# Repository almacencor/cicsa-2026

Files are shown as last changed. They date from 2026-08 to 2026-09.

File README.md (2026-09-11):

CICSA WRO 2026 Banner

# WRO 2026 Future Engineers — Team CICSA
### National Final · Mexico · Season 2026

This is the official repository of **Team CICSA** for the WRO 2026 Future Engineers National Final. It contains all engineering materials for our self-driving vehicle: source code, wiring diagrams, 3D models, photos, and a full engineering journal documenting our design process.

---

## Follow us!

| Facebook | YouTube | Instagram |
|---|---|---|
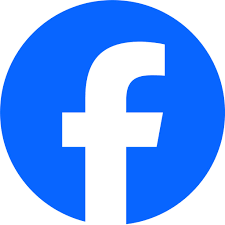
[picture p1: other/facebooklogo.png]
Facebook (https://www.facebook.com/share/1A1hz6zQSn/)
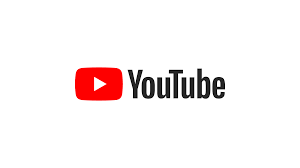
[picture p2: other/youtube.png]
YouTube (https://www.youtube.com/@CICSA_Academia)
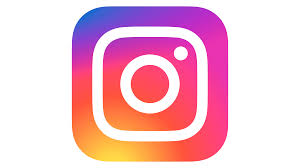
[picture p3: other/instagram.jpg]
Instagram (https://share.google/ZzGMFZOurGsjhWN2D)
|  |  |  |

---

## Contents

**Folders**
- [📁 Models](./models/) — 3D printable parts (STL/F3D files)
- [📁 Other](./other/) — Engineering logbook and supplementary materials
- [📁 Schemes](./schemes/) — Wiring diagrams and electrical schematics
- [📁 Src](./src/) — All source code (Raspberry Pi Python — single-controller architecture)
- [📁 T-photos](./t-photos/) — Team photos (official + funny)
- [📁 V-photos](./v-photos/) — Vehicle photos (6 angles required)
- [📁 Video](./video/video.md) — Performance video links

**Index**
- [The team](#the-team)
- [The challenge](#the-challenge)
- [Robot overview](#robot-overview)
- [Mobility management](#mobility-management)
- [Power and sensor management](#power-and-sensor-management)
- [Software architecture](#software-architecture)
- [Obstacle management](#obstacle-management)
- [Systems thinking and engineering decisions](#systems-thinking-and-engineering-decisions)
- [Robot construction guide](#robot-construction-guide)
- [Engineering materials](#engineering-materials)
- [Performance videos](#performance-videos)
- [Digital engineering logbook](./other/README.md)
- [Final remarks and future work](#final-remarks-and-future-work)
- [References](#references)

---

## The team

**CICSA WRO 2026 — Future Engineers**

**Coach: Sergio Iván Hernández Ruiz**

Coach Sergio Iván provides the technical guidance and leadership required to keep Team CICSA on track. With extensive experience in robotics, he helps us navigate complex engineering challenges, refine our designs, and develop solutions that work in competitive environments. He has been director of the CICSA robotics academy since 2015 and has participated in WRO events since 2019.

---

**Gildardo Garcia** — Age 17 · Centro de Estudios Tecnológicos Industrial y de Servicios 128

Gildardo is responsible for the programming. He participated in the 2019 WRO Regional in Guadalajara in the primary category, where he obtained 2nd place. For the 2026 championship, he is responsible for programming and calibrating the sensors to ensure they function correctly.

---

**Sergio Amid Hernández González** — Age 20 · Software Engineering, Kuepa University

Sergio Amid leads the design and construction of the robot's 3D parts. He has participated in numerous competitions: 2019 WRO Regional in Guadalajara (1st place, preparatory category), 2024 WRO National in Mexicali (1st place, preparatory category), and represented Mexico at the WRO World Championship in Italy in 2024.

---

**Diego Pereida Arochi** — Age 18 · United States Air Force Avionics technician

Diego is responsible for PID control, motor/servo driver integration, and LIDAR sensor tuning, all running natively on the Raspberry Pi. He has competed in the FIRST Robotics Competition in both the United States and Mexico, achieved 1st place at WRO 2025 Mexicali, and alongside Sergio Amid represented Mexico at the WRO Italy 2024 Open World Championship. Currently in boot camp in San Antonio, Texas, and wasn't able to attend the national championship.

[📁 T-photos](./t-photos/)

[▲ Menu](#contents)

---

## The challenge

The WRO 2026 Future Engineers challenge requires teams to build a fully autonomous self-driving vehicle that competes in two rounds:

**Open Challenge:** The vehicle must complete three (3) laps on a track with randomly placed inner walls. Direction (clockwise or counter-clockwise) is revealed at competition time. No obstacles are present; the goal is clean navigation and lap time.

**Obstacle Challenge:** The vehicle must complete three (3) laps on the same track, this time with randomly placed red and green traffic sign pillars. The robot must:
- Pass to the **right** of a **red** pillar
- Pass to the **left** of a **green** pillar
- Not knock over any pillar
- After completing three laps, locate the magenta-bordered parking zone and execute a **parallel parking maneuver**

Scoring is based on: laps completed, obstacles respected, parking success, lap time, and documentation quality (engineering journal and this GitHub repository).

Our robot addresses these requirements using:
- **LIDAR** (RPLidar A1M8) for 360° distance mapping, sector-based wall following, and initial track-direction detection
- **Computer vision** (OpenCV on Raspberry Pi), used in the Obstacle Challenge program for traffic sign color detection and parking-zone location
- **PID control**, running natively in Python on the Raspberry Pi via `gpiozero`, for closed-loop steering during wall following
- **Hardware-timed PWM** (via the `pigpio` pin factory backing `gpiozero`) driving the servo and motor drivers from Raspberry Pi GPIO pins

For full game rules, visit the [WRO Official Site](https://wro-association.org/).

[▲ Menu](#contents)

---

## Robot overview

| Front | Back | Top |
|---|---|-----|
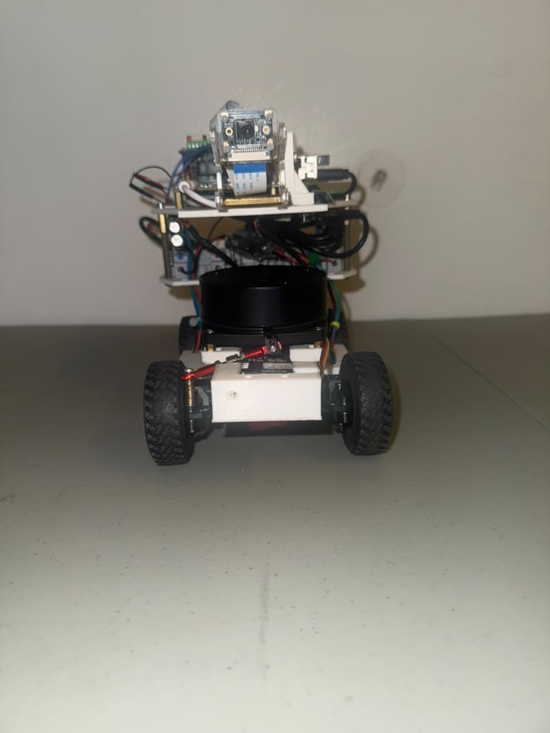
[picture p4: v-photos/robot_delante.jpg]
Front view
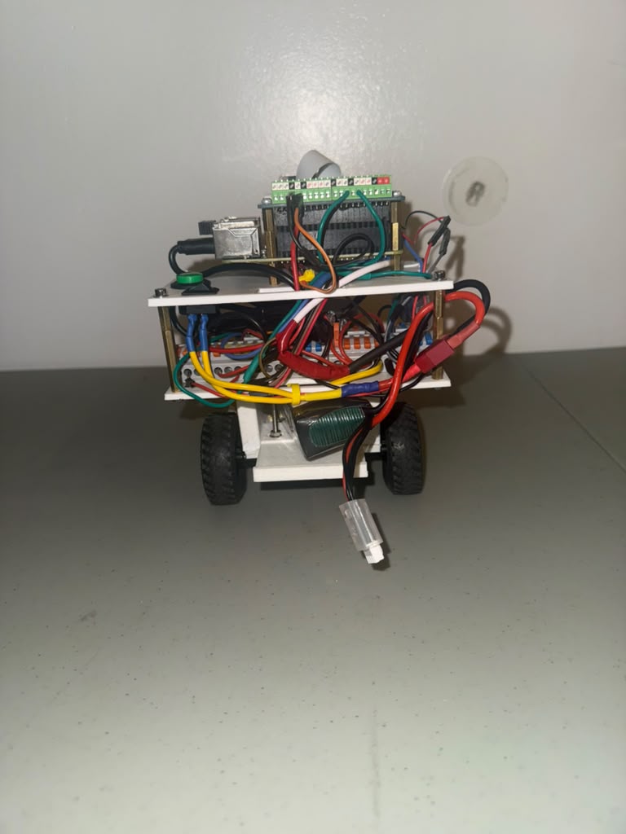
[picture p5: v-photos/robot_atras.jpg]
Back view
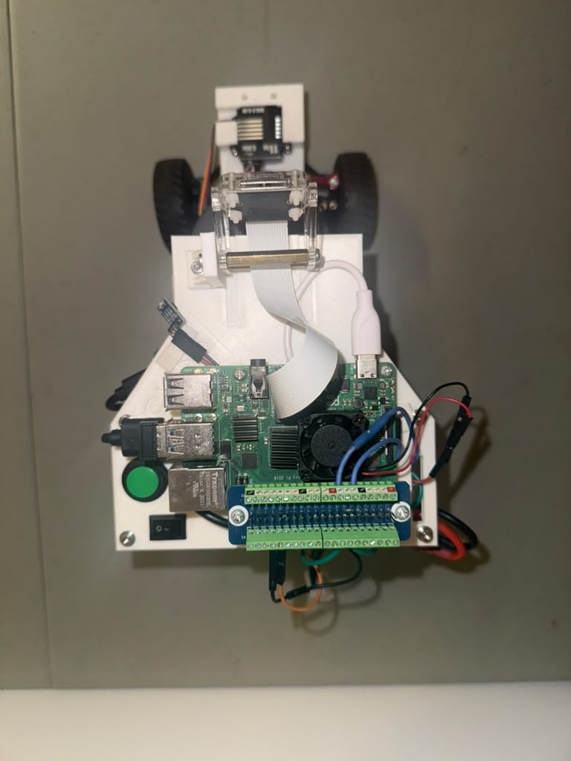
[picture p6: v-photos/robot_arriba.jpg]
Top view
|  |  |  |

| Bottom | Left | Right |
|---|---|---|
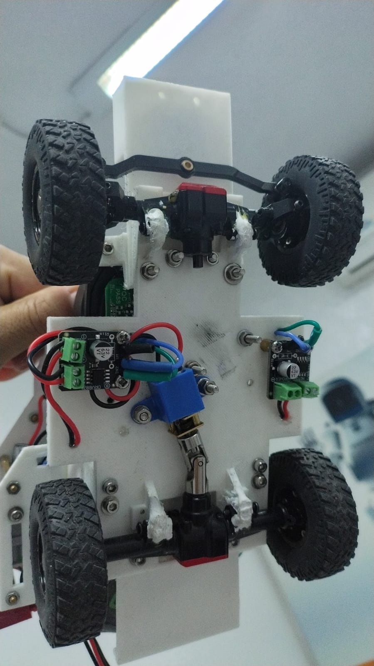
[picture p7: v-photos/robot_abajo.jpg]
Bottom view
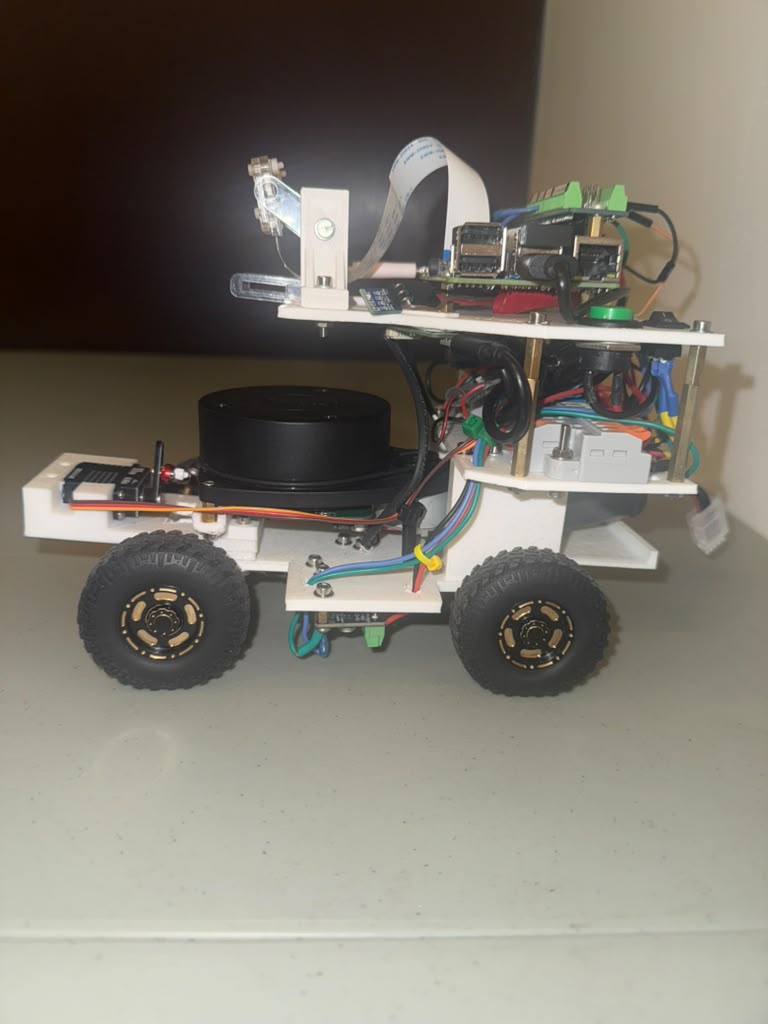
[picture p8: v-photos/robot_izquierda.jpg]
Left view
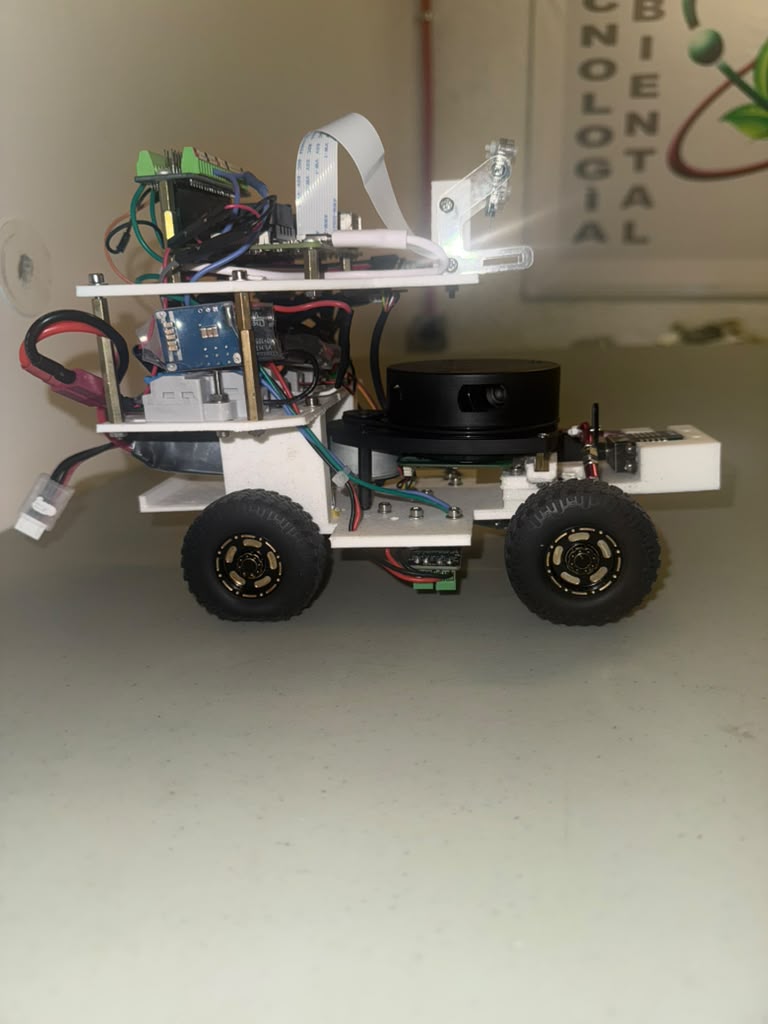
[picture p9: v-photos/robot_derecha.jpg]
Right view
|  |  |  |

| Dimension | Value |
|---|---|
| Length | ~230 mm |
| Width | ~145 mm |
| Height | ~190 mm |
| Weight | ~1174 g |

> **Note for judges:** Exact dimensions measured with calipers are documented in the engineering logbook. Robot must be under 300 mm × 200 mm per WRO vehicle regulations.

[▲ Menu](#contents)

---

## Mobility management

### Chassis and drive system

Our chassis employs a **rear-wheel drive** (RWD) system using a 400-RPM N20 motor, capped at 50% power to optimize battery life and improve LiDAR readings during turns—as higher speeds caused the LiDAR to struggle, thereby increasing the margin of error. The motor connects to the wheels via a differential to enable tighter turns, while the front end features an Ackermann steering system.

**Drive motor: N20 DC 12V, 400 RPM**

We selected the **N20 400 RPM variant** after testing 500 RPM and 1000 RPM versions of the same motor family. The higher-RPM motors caused the robot to overshoot turns and made PID tuning unstable at low speeds. We limit the motor power to just **200 rpm** (50% power) so that the robot has better PID control when turning in the shortest possible time and with the 2.09in diameter wheels, the linear speed is approximately:

```
2.09 in x 2.54 = 5.3086
R=5.3086 / 2=2.654
C=3.1416 x 5.3086 = 16.667
16.667 cm/rev x 200rev/min = 3335.4 cm/min
3335.4 / 60 = 55.59cm/s
linear speed 55.6 cm/s
```

This ~55.6 cm/s base speed provides enough controllability for the PID loop while still completing three laps in a competitive time. The N20 at 12V produces ~1.5 kg·cm of stall torque, sufficient to move our 1.179 kg robot including a safety margin for carpet-surface friction. In code, drive speed is set as a duty-cycle fraction (`target_velocity`, currently 0.5) rather than a raw RPM value.

**Steering: DIYmall 11KG Mini All-Metal Digital Servo**

The front axle uses the DIYmall 11KG coreless digital servo for steering. We chose an 11 kg·cm servo (rather than a lighter 3–5 kg·cm servo) because our front wheel assembly includes a 4mm-to-3mm steering shaft that creates mechanical friction. The heavier servo ensures fast, accurate response to PID commands without positional lag.

In software, the servo is driven through `gpiozero`'s `AngularServo` class (backed by the `pigpio` pin factory for hardware-timed pulses), configured for a ±90° mechanical range with 0.5–2.5 ms pulse widths and a software center of 0°. Two calibration constants trim this in code:
- `STEERING_LIMIT = 40` — clamps every requested steering command to ±40°, well inside the mechanical range, to protect the linkage.
- `CENTER_OFFSET = -20` — a fixed trim added after clamping, to correct for the assembly's slight physical off-center bias, rather than a separate one-time calibration script.

**Wheels: TRX4M 1/18 scale**

These wheels provide a balance between grip and rolling resistance. Their 2.09IN outer diameter was used in all speed calculations above.

**Turning radius estimation**

With our wheelbase of approximately 120mm and a software steering limit of ±40°, the minimum turning radius is approximately 165mm. This is well within the WRO track corner geometry.

### Steering and assembly photos

> See [📁 Models](./models/) for all 3D-printed STL files for the chassis plate, LIDAR tower, camera mount, and servo bracket.
> See [📁 V-photos](./v-photos/) for step-by-step assembly photos.

[▲ Menu](#contents)

---

## Power and sensor management

### Power system architecture
|Component | Operating Voltage	| Approx. Typical Current	| Approx. High/Maximum Current	| Approx. Power |
|---|---|---|---|---|
|Raspberry Pi 4B	| 5 V	| 0.7–1.2 A	| ~1.5–2.0 A	| 3.5–10 W |
|Freenove Camera	| 5 V	| ~0.1–0.3 A	| ~0.3–0.5 A	| 0.5–2.5 W |
|LiDAR A1M8	| 5 V	| ~0.12–0.18 A	| ~0.2 A	| 0.6–1 W |
|Mini Servo, 24.3 lb, 180°	| 5 V	| ~0.2–0.8 A	| ~1.5–2.0 A*	| 1–10 W |
|N20 Motor , 400 RPM	| 11.1 V via DRV8871	| ~0.2–0.8 A	| ~1.5 A or higher*	| ~2–17 W |
|MPU 6050 | 5V | 3.9mA | 5mA | 13mA |

**Battery:** OVONIC 3S 11.1V, 2200 mAh

We use an 11.1V OVONIC 3S battery; although it nominally provides 12.6V, the voltage drops to 11.1V under load. It is capable of powering the N20 motor, as the motor primarily relies on current—which the 8871 driver supplies. A 2200 mAh capacity gives an estimated runtime of:1.11 hours if the motors are in a middle range of work and the processor is not demanding to much energy 

```
1.20+0.30+0.18+0.50+0.0039=2.1839
P5v = 5x2.18 = 10.9W
Pmotor = 11.1x0.80 = 8.88W
Ptotal = 10.9+8.88 = 19.78W
90% regulator efficiency = 21.98W
11.1V x 2.2Ah = 24.42Wh
Runtime = 24.42Wh/21.98W = 1.11H

```

Three competition rounds are estimated at under 10 minutes total, giving more than 5× safety margin.

**Voltage regulation:**

A DC-DC buck converter steps the 11.1V battery down to a stable 5V 5A rail for the Raspberry Pi, LIDAR, and servo. The motor drivers (DRV8871) take 12V directly from the battery to drive the N20 motors. The Raspberry Pi's own 3.3V GPIO pins drive the DRV8871 logic inputs and the servo PWM line directly — no intermediate microcontroller or level shifting is required, since the DRV8871's logic inputs and standard hobby servos both accept 3.3V signal levels.

**Wiring diagram:**

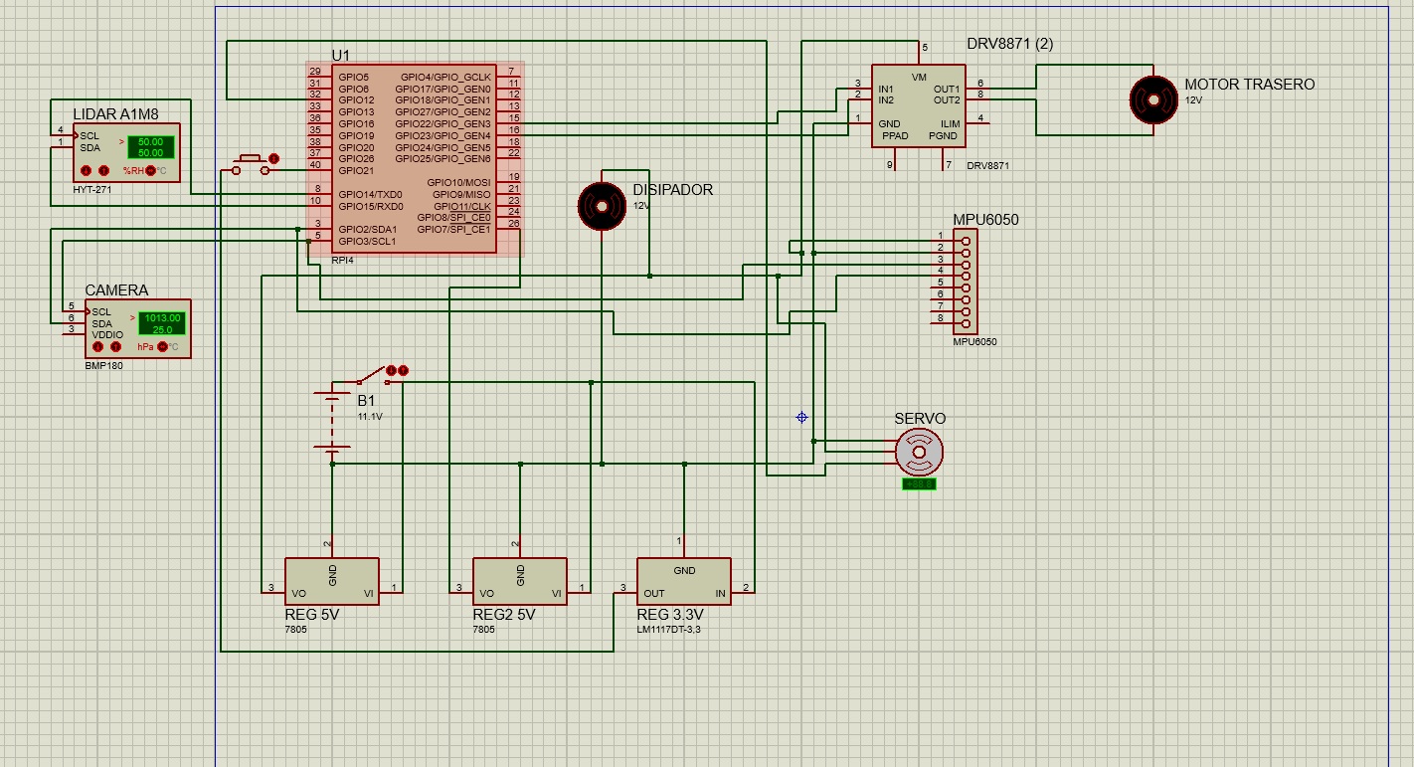
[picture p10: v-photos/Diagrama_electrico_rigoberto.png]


> See [📁 Schemes](./schemes/) for the full wiring schematic (Fritzing + PDF export).

Actual GPIO assignments:
- Battery (+) → DRV8871 (1) VM IN and Buck Converter IN
- Buck converter 5V OUT → Raspberry Pi USB-C, LIDAR 5V, Servo signal rail
- Raspberry Pi **GPIO 2, 3** → SCL and SDA 
- Raspberry Pi **GPIO 23** → Rear-motor DRV8871 IN1 (forward)
- Raspberry Pi **GPIO 22** → Rear-motor DRV8871 IN2 (backward) — this is the channel actually driving the robot
- Raspberry Pi **GPIO 12** (hardware PWM via `pigpio`) → Servo signal wire

Each axle's driver has its own independent forward/backward pin pair, which is what allows the front motor to be enabled or disabled purely in software.

### Sensor selection and placement

**RPLidar A1M8 (1 unit) — top-center mount**

The LIDAR provides 360° distance scanning at up to 8m range. We mount it at the top center of the robot so it has unobstructed line-of-sight to the track walls. It is the primary sensor for both the open-challenge wall-following algorithm and the initial track-direction detection at start-up, and it also supports close-range distance checks in the Obstacle Challenge program (parking-wall proximity).

Rather than reading raw single-beam distances, the code partitions each scan into three angular sectors and runs a small DSP pipeline before using the data (see [Software architecture](#software-architecture) for details):
- Front sector: −5° to +5°
- Left sector: 255° to 285°
- Right sector: 75° to 105°

**Freenove 8MP Camera (1 unit) — front center, elevated 80mm**

Used by the Obstacle Challenge program (not present in `wro2026_open_e.py`). The camera is mounted forward-facing at 80mm height, which gives a field of view that captures both the floor zone immediately ahead of the robot and traffic signs at their actual height on the track. Elevation was determined through testing: lower mounting caused the camera to see too much floor and miss vertical pillar colors; higher than 90mm clipped the near field.

**Sensor calibration:**

- LIDAR: Uses RPLidar SDK default factory calibration. Points below 150mm or above 6000mm are discarded as out-of-range/self-mapping noise (see DSP pipeline below).
- Steering: mechanical/electrical zero-offset is trimmed with the `CENTER_OFFSET` constant in code rather than a separate calibration script.
- Camera (Obstacle Challenge program): white balance set to auto; HSV color thresholds for red/green calibrated under venue lighting the day before the event and stored as constants in the config file.

[▲ Menu](#contents)

---

## Software architecture

### System overview

All decision-making and control runs in a single process on the **Raspberry Pi 4B (Python 3)**, using the `gpiozero` library for motor/servo control with its **pigpio pin factory** (set via `GPIOZERO_PIN_FACTORY = 'pigpio'`) so PWM pulses are generated with hardware timing (via the Pi's DMA controller) instead of in Python's own execution thread. This means servo and motor pulses stay precisely timed even if the Python control loop itself is briefly delayed by the OS scheduler.

This repository currently documents two separate programs:
- **`wro2026_open_e.py` (Open Challenge)** — LIDAR-only: sector-based distance sensing, DSP filtering, a start-up direction-detection routine, and a velocity-form PID wall follower. **No camera, no OpenCV, no obstacle/parking logic exists in this file.**
- **Obstacle Challenge program** — extends the same LIDAR/PID/motor foundation with the camera-based color detection and parking sequence described in [Obstacle management](#obstacle-management).

### Open Challenge — quick overview

These diagrams are meant to be walked through verbally in under a minute.

**Flow — what the robot does, in order:**

```mermaid
flowchart TD
    A["Start"] --> B["Initialize<br/>(motors off, servo centered)"]
    B --> C["Find track direction<br/>(LIDAR spots the first opening)"]
    C --> D["Follow the wall<br/>(PID keeps it centered)"]
    D --> E["Turn the corner"]
    E --> F{"Finished all laps?"}
    F -- No --> D
    F -- Yes --> G["Slow final stretch, then stop"]
```

**States — what mode the robot is in:**

```mermaid
stateDiagram-v2
    [*] --> Starting
    Starting --> FindingDirection
    FindingDirection --> FollowingWall
    FollowingWall --> TurningCorner
    TurningCorner --> FollowingWall: more laps left
    TurningCorner --> Finishing: laps complete
    Finishing --> Stopped
    Stopped --> [*]
```

### Open Challenge — program flow

- **`initialize_system()`** — zeroes actuators (motors stopped, steering centered) before anything else runs.
- **LIDAR worker thread (`lidar_worker_thread`)** — a daemon thread that continuously reads scans from the RPLidar, splits each scan into front/left/right sectors by angle, runs the DSP pipeline below, and writes the resulting distances into shared global variables under a lock (`lidar_lock`) for the main thread to read.
- **`execute_start_sequence()`** — drives forward slowly while watching the left and right sectors. The first time one side reports a gap >1000mm while the front is ≤750mm, that's read as the track's first open corner; the robot executes a blind, timed 90° turn toward that opening and locks in which wall it will track (`control_direction`) for the rest of the run. Lap progress after that is tracked by counting a fixed number of turns rather than detecting a start/finish line.
- **`pid_wall_follower()`** — the closed-loop distance-holding routine, described in detail below.
- **`execute_90deg_left_turn()` / `execute_90deg_right_turn()`** — open-loop, timed turns (steer to ±40°, hold ~0.95s, recenter) used to negotiate each corner once the PID segment approaches it.
- **`terminate_system()`** — stops both motors and recenters steering; also runs on `KeyboardInterrupt` or any unhandled exception, so the robot fails safe.

### LIDAR signal processing (`filter_lidar_zone`)

Each angular sector's raw `(distance, angle)` points go through a small NumPy/SciPy pipeline before being used for control:

1. **Range filter** — discard points outside 150–6000mm (150mm excludes the robot's own chassis from self-mapping).
2. **Dropout interpolation** — missing/out-of-range samples are linearly interpolated (`np.interp`) from neighboring valid points rather than left as gaps.
3. **Median filter** — a wrapped median filter (window size 3) smooths the sector and rejects specular multi-path reflections.
4. **Step-discontinuity rejection** — the first-order difference between consecutive filtered points is checked against a 500mm gradient threshold; points that jump too fast between adjacent readings are dropped as likely noise.

The closest valid point in each sector is then taken as that sector's representative distance (front/left/right).

### PID controller (velocity-form, Raspberry Pi)

The actual PID implementation in `pid_wall_follower()` is a **velocity-form (incremental) PID**, not the textbook positional form:

```python
output = int(
    kp * (error - p_error)
    + (ki * error)
    + (kd * (error - (2 * p_error) + p_error_2))
    + p_output
)
output = min(max(output, -40), 40)
```

**Tuned values (current, in code):**
- `kp = 1.2` (proportional term, applied to the error delta)
- `ki = 0.0` (integral term currently disabled)
- `kd = 0.5` (derivative-of-error term, using a second-order error history)
- Sample time `T = 0.005s` — a ~200Hz control loop

The raw output is passed through `sanitize_control_signal()`, a rolling-median filter over the last 5 outputs: if a new value would jump more than 15° away from the recent median, it's replaced with that median instead, damping single-cycle spikes before they reach the servo. The sanitized value is what's actually sent to `set_steering_angle()`.

A safety early-exit ("CUELLO"/bottleneck check) is built into the long wall-follow segment: if the front sector reports ≤725mm after at least 250 cycles during the main 11-lap-loop call (not the short finishing call), the function exits early rather than continuing to drive toward a wall it's approaching too fast.

### Motor and steering actuation

- **`drive_forward_rwd()` / `drive_backward_rwd()` / `stop_rwd()`** — The motor is connected to the rear-wheel differential to provide mobility for the robot.
- **`set_steering_angle()`** — clamps the requested angle to `±STEERING_LIMIT` (40°), adds the `CENTER_OFFSET` trim (−20°), and writes the result to the `AngularServo`.

### Code structure

```
src/
└── raspberry_pi/
    ├── wro2026_open_e.py    # Open Challenge: state machine, LIDAR DSP, PID wall follower, motor/servo control
    └── (obstacle challenge program — vision/color detection, parking; separate file)
```

`wro2026_open_e.py` is a single self-contained script. Splitting it into separate modules (vision, LIDAR, PID, motor control) is on our list for a future cleanup pass.

[▲ Menu](#contents)

---

## Obstacle management

**Everything in this section describes the separate Obstacle Challenge program, which is not part of `wro2026_open_e.py`.** The Open Challenge script has no camera input and no color/parking logic.

# WRO 2026 Future Engineers - Obstacle Challenge

Autonomous vehicle developed for the *WRO 2026 Future Engineers Obstacle Challenge*. The system runs on a Raspberry Pi 4 and combines a 2D LiDAR, a camera, and an MPU6050 inertial sensor to follow walls, determine the driving direction, avoid colored traffic pillars, negotiate corners, recover from critical situations, and complete the required laps.
 
> Main program: wro2026_obstacle.py

## Project goals

The controller was designed around five priorities:

- Compliance with the WRO Future Engineers obstacle rules.
- Repeatable behavior with different battery levels.
- Sensor validation instead of acting on isolated measurements.
- A clear finite-state machine for testing and debugging.
- Recovery from temporary faults without immediately ending the run.

## Hardware

| Component | Purpose | Connection |
|---|---|---|
| Raspberry Pi 4 | Main computer and control coordinator | Central controller |
| RPLidar A1 | Front and lateral distances, wall geometry, open spaces, and corner detection | USB serial, normally /dev/ttyUSB0 |
| Freenove IMX219 camera | Red/green pillar detection and image position | Raspberry Pi CSI interface |
| MPU6050 | Angular velocity, accumulated heading, and 90-degree turn confirmation | I2C: SDA GPIO 2, SCL GPIO 3 |
| Ackermann steering servo | Front steering angle | GPIO 12 |
| Rear DC motor and driver | Forward and reverse movement | GPIO 23 and GPIO 22 |
| MPU6050 | Know the robot position | GPIO 2 and GPIO 3 |

The LiDAR convention used by the software is:

- 0°: front
- 90°: right
- 180°: rear
- 270°: left

Positive steering angles turn left; negative angles turn right.

## System architecture

The sensors run in independent background threads. Each thread publishes its newest measurement with a sequence number and timestamp. A single fixed-rate controller reads the latest snapshots at *40 Hz*, validates them, executes the active state, and sends commands to the steering servo and rear motor.

mermaid
flowchart TD
    CAM["Camera<br/>pillar color, x, bottom, area"]
    LIDAR["RPLidar A1<br/>front, left, right, wall angle"]
    MPU["MPU6050<br/>heading and angular change"]

    SNAP["Time-stamped sensor snapshots"]
    VALID["Validation and filtering"]
    FSM["40 Hz finite-state controller"]
    ACT["Steering servo and rear motor"]
    TELE["CSV telemetry"]

    CAM --> SNAP
    LIDAR --> SNAP
    MPU --> SNAP
    SNAP --> VALID --> FSM
    FSM --> ACT
    FSM --> TELE

## How each sensor is used

### RPLidar A1

The LiDAR is the main geometric sensor. Its scans are divided into angular sectors to obtain front, left, and right distances. Recent measurements are filtered with medians and checked for minimum point count, age, physical range, and impossible jumps.

It supports:

- Corridor centering before the driving direction is known.
- Outer-wall following during normal sections.
- Selection of the closest reliable wall during pillar avoidance.
- Detection of the front wall before a corner.
- Verification that enough space exists during reverse and corner exit.
- Recovery when a distance becomes critical or the LiDAR stops updating.

### Camera

The IMX219 camera detects red and green traffic pillars. The image pipeline applies a region of interest, color segmentation, blob filtering, and geometric plausibility checks.

For every candidate, the controller considers:

- Color: red or green.
- Horizontal position (x).
- Bottom position in the image.
- Blob area and shape.
- Agreement between two independent distance estimates.

The color determines the legal passing side:

| Pillar | Robot passes on | Pillar remains on |
|---|---|---|
| Red | Right | Left side of the robot |
| Green | Left | Right side of the robot |

A short hold period prevents the maneuver from ending because of one missed camera frame. After the pillar disappears, the controller completes the crossing using LiDAR distance and MPU6050 heading.

### MPU6050

The MPU6050 is calibrated while the robot is completely stationary. The Z-axis gyroscope is filtered and integrated to estimate accumulated heading.

It is used to:

- Maintain a heading reference during cascaded wall control.
- Measure the angular displacement produced while avoiding a pillar.
- Apply counter-steering after the pillar has been passed.
- Confirm each 90-degree corner by heading instead of time alone.
- Compare the expected total heading with the number of completed corners.

Using heading feedback makes the corner maneuver less dependent on motor speed or battery voltage.

## Finite-state machine

mermaid
stateDiagram-v2
    [*] --> START
    START --> DETERMINE_DIRECTION: sensors ready
    DETERMINE_DIRECTION --> REVERSE: first corner detected

    STRAIGHT --> PILLAR: valid pillar detected
    PILLAR --> STRAIGHT: pillar passed
    STRAIGHT --> REVERSE: corner confirmed

    REVERSE --> TURN: reverse clearance reached
    TURN --> EXIT_TURN: 90-degree turn confirmed
    EXIT_TURN --> STRAIGHT: more corners required
    EXIT_TURN --> FINISHED: final corner completed

    DETERMINE_DIRECTION --> RECOVER: recoverable condition
    STRAIGHT --> RECOVER: recoverable condition
    PILLAR --> RECOVER: recoverable condition
    REVERSE --> RECOVER: recoverable condition
    TURN --> RECOVER: recoverable condition
    EXIT_TURN --> RECOVER: recoverable condition
    RECOVER --> DETERMINE_DIRECTION: retry initial approach
    RECOVER --> STRAIGHT: retry section
    RECOVER --> REVERSE: retry corner
    FINISHED --> [*]

| State | Main responsibility | Principal sensors |
|---|---|---|
| START | Initialize actuators, telemetry, and sensor threads | All |
| DETERMINE_DIRECTION | Center the robot and identify the outer wall at the first corner | LiDAR, camera, MPU6050 |
| STRAIGHT | Follow the active reference wall and search for the next event | LiDAR, camera, MPU6050 |
| PILLAR | Cross to the legal side and pass the detected pillar | Camera, LiDAR, MPU6050 |
| REVERSE | Create enough space before turning | LiDAR |
| TURN | Execute and confirm the 90-degree corner | MPU6050, LiDAR fallback |
| EXIT_TURN | Leave the corner and restore normal motion | LiDAR |
| RECOVER | Reverse, reposition, and retry a recoverable state | LiDAR, active-state context |
| FINISHED | Stop motion, close telemetry, and stop threads | All |

## Development process

### 1. Basic propulsion and steering

Development started by calibrating the rear motor, steering center, and asymmetric left/right steering limits. Braking was improved with a short opposite-direction motor pulse to reduce inertia and make stopping distance more repeatable.

### 2. LiDAR wall following

The first autonomous behavior used the RPLidar A1 to follow the outer wall. Raw scans were divided into sectors and filtered. A fixed-rate loop was then introduced so control timing no longer depended on the LiDAR scan rate.

The straight controller evolved into a cascaded structure:

1. Lateral distance error generates a target heading offset.
2. MPU6050 heading error generates the steering command.
3. Steering limits and critical-distance protections constrain the result.

### 3. Camera-based pillar detection

Red and green segmentation was added using the Raspberry Pi camera. Early tests showed that color alone could create false detections, so the detector was expanded with minimum area, aspect ratio, bounding-box fill, region-of-interest, temporal confirmation, and geometric plausibility filters.

Two image measurements estimate pillar distance independently: blob area and vertical bottom position. A candidate is accepted only when both estimates are reasonably consistent.

### 4. Pillar avoidance

The first avoidance controller always referenced the outer wall. That became unreliable when the robot crossed away from it, especially when a black wall produced few LiDAR returns at long range.

The final strategy follows one rule: *during avoidance, use the wall on the side toward which the robot is crossing*. This keeps the reference wall closer and gives the LiDAR a more reliable surface.

The maneuver continues briefly after the camera loses sight of the pillar. LiDAR distance controls the remaining lateral crossing, while the MPU6050 measures the heading change and guides the counter-steering phase.

### 5. MPU6050 heading control

Time-based turns varied with battery voltage and surface conditions. The MPU6050 was therefore added to measure heading directly. The software calibrates gyroscope bias at startup, filters vibration, learns or applies the rotation sign, and confirms the corner when the accumulated change reaches the target angle.

### 6. Recovery and robustness

Instead of aborting after every sensor anomaly, the controller classifies selected faults as recoverable. Recovery brakes the robot, chooses a safe reverse steering direction from the obstacle location, reverses until space is available, centers the steering, and retries the interrupted state.

Additional protections include:

- Sensor age and health checks.
- LiDAR jump rejection held for the complete scan.
- Maximum valid wall distance.
- Critical front and lateral distances.
- Camera outage speed limitation.
- Maximum duration for blind crossing phases.
- Limited recovery and corner retry counts.
- CSV telemetry for post-run analysis.

### 7. Direction detection and complete-lap sequence

At startup, the robot does not yet know which wall is outside. It centers between both walls and approaches the first corner. The side that opens identifies the inner area of the track; the opposite side becomes the outer reference wall. The controller then executes the first corner and repeats straight-section and corner states until the configured number of corners is complete.

## Software requirements

- Raspberry Pi OS with Python 3
- gpiozero
- pigpio daemon and Python interface
- opencv-python / Raspberry Pi OpenCV package
- picamera2
- smbus2
- rplidar (rplidar-roboticia compatible API)

## Running the controller

Start the pigpio service before a hardware run:

bash
sudo systemctl start pigpiod

Run a normal three-lap session:

bash
cd /home/pi/wro2026/wro2026_obstacle
source /home/pi/rplidar_env/bin/activate
python3 wro2026_obstacle_english.py

Run one lap for testing:

bash
python3 wro2026_obstacle_english.py --vueltas 1

Run the logic tests without hardware:

bash
python3 wro2026_obstacle_english.py --autotest

Run the simulator when the companion simulation module is available:

bash
python3 wro2026_obstacle_english.py --sim

Disable telemetry if required:

bash
python3 wro2026_obstacle_english.py --sin-telemetria

> Keep the robot completely still during MPU6050 calibration. For bench testing, raise the driven wheels or disconnect motor power until the steering and sensor checks are complete.

## Telemetry

During a run, the controller can save CSV rows containing:

- Current state and corner number.
- Front, left, and right LiDAR distances.
- Active reference wall and target distance.
- Steering and speed commands.
- Pillar color, horizontal position, bottom position, and area.
- MPU6050 heading and relative heading.
- LiDAR and camera health flags.

These logs were essential for comparing runs, identifying false measurements, adjusting thresholds, and verifying whether a failure came from perception, control, or mechanical behavior.

# Code challenge flowchart

### 1. Simplified Program Flow

The camera, LiDAR, and MPU6050 operate concurrently. Each sensor thread publishes its latest time-stamped measurement. The 40 Hz Finite-State Machine (FSM) reads and validates these sensor snapshots before determining the vehicle's steering and speed commands.

Figure 1. Simplified execution flow.

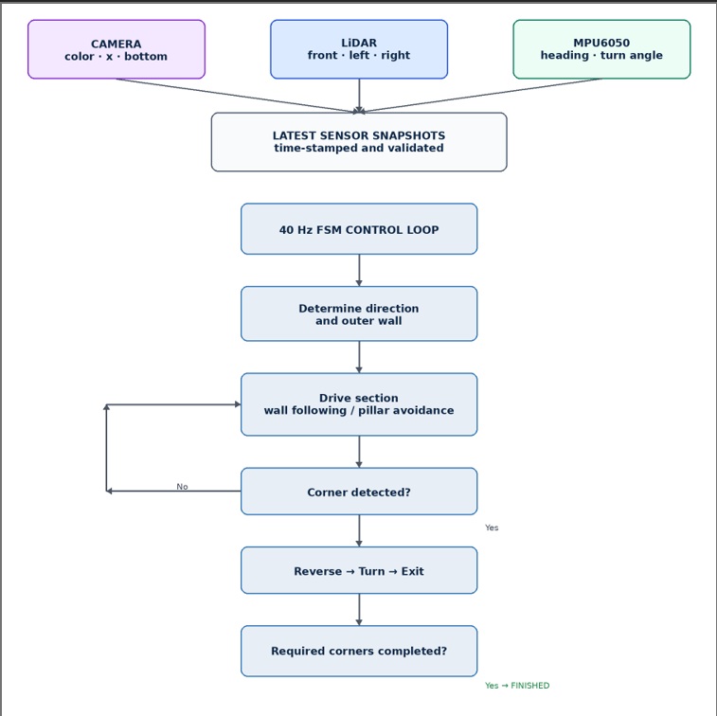
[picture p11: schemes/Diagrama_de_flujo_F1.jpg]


### 2. Finite-State Machine

The FSM connects each sensor to the states where it is primarily used:

Camera: Pillar recognition and passing-side selection.
LiDAR: Wall following, clearance monitoring, and corner detection.
MPU6050: Heading stabilization and confirmation of the 90-degree turn.

Figure 2. Main FSM states and transitions.

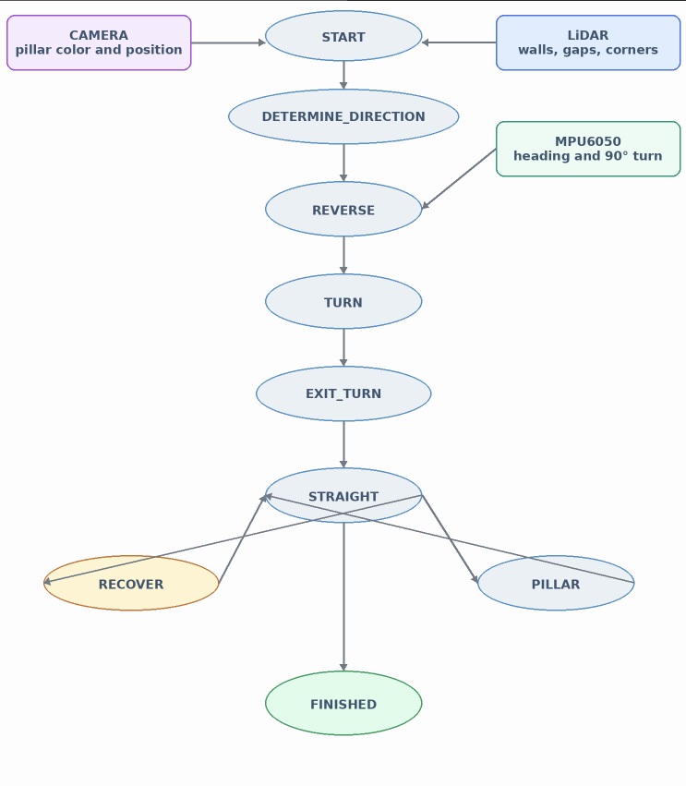
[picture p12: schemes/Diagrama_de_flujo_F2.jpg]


### 3. State Summary

State	Purpose
START	Initialize actuators, telemetry, MPU6050, LiDAR, and camera.
DETERMINE_DIRECTION	Center the vehicle in the corridor, handle an early pillar, and identify the outer wall at the first corner.
STRAIGHT	Follow the active reference wall and monitor the next corner.
PILLAR	Select the legal passing side and control the crossing using camera, LiDAR, and heading information.
REVERSE	Move backward from the corner to create sufficient turning space.
TURN	Execute and confirm the 90-degree turn, primarily using MPU6050 heading data.
EXIT_TURN	Straighten the steering and safely exit the corner.
RECOVER	Reverse and reposition the vehicle after a recoverable sensor or distance condition, then retry the maneuver.
FINISHED	Brake, center the steering, save telemetry, and stop all sensor threads.

### 4. Control-Cycle Logic

The control loop runs at 40 Hz and follows these steps:

Read the newest sensor snapshots without waiting for a new LiDAR scan.
Validate sensor age, measurement range, geometric plausibility, and detect impossible measurement jumps.
Select the reference wall:
Outer wall during normal driving.
Passing-side wall during pillar avoidance.
Compute the appropriate steering and speed commands.
Apply safety limits to the control commands.
Record telemetry data.
Repeat the cycle at 40 Hz.

This architecture allows the vehicle to process sensor data concurrently while maintaining a deterministic control cycle through the FSM.

[▲ Menu](#contents)

---

## Systems thinking and engineering decisions

### Why gpiozero + pigpio (not a raw pigpio API or a separate ESP32)?

Our 2025 platform split real-time control onto a dedicated ESP32 microcontroller to avoid Linux scheduling jitter. For 2026 we removed the ESP32 to simplify the electronics stack, reduce weight, cut cost, and remove a UART link and an extra power rail as potential failure points.

We still needed to solve the jitter problem, so instead of bit-banging PWM in Python, our motor and servo control goes through `gpiozero`'s `Motor` and `AngularServo` classes, configured to use the `pigpio` pin factory. `pigpio` generates the actual pulses via the Raspberry Pi's DMA hardware, so timing stays precise regardless of what the Python interpreter is doing at that instant, while `gpiozero` gives us a simpler, higher-level API than calling the pigpio daemon's socket interface directly. The trade-off we accepted is a lower decision-update rate in our own control loop versus a dedicated microcontroller, which we judged acceptable given our top speed of ~6.6 cm/s and the track's corner geometry.

**Alternative considered:** Keeping the ESP32. Rejected for 2026 because the added wiring complexity and UART maintenance burden outweighed the timing benefit at our modest drive speed.

### Why LIDAR + camera (not ultrasonic sensors)?

Our previous design used two ultrasonic sensors for close-range obstacle avoidance and parking alignment, angled outward from center. In testing this season we found the LIDAR's minimum range (15cm) combined with its full 360° coverage gave us close-range awareness that was accurate enough to drop the ultrasonic sensors entirely for the Open Challenge. This simplified our wiring, freed up current budget on the 5V rail, and removed two more components that could fail or drift out of calibration.

**Alternative considered:** Keeping ultrasonic sensors purely as a parking-alignment backup. Rejected because our practice runs showed the LIDAR's side-sector readings were consistently within a few millimeters of the ultrasonic readings they were replacing, making the redundancy unnecessary for our current track speed.

**Alternative considered (open challenge):** Single-camera line following. Rejected because the WRO 2026 track uses no floor markings — walls are the only navigational reference.

### Why DRV8871 motor driver (not L298N or DRV8833)?

The DRV8871 was chosen over the L298N we used in 2025 for three key reasons. First, efficiency: the DRV8871 uses N-channel MOSFETs and loses only ~5% of power as heat, compared to the L298N's ~30% loss — this means less thermal management and longer battery life. Second, built-in current regulation: the DRV8871 has integrated current sensing that limits peak current to 3.6A, protecting our N20 motors from stall damage without external circuitry. Third, size: the DRV8871 module is significantly smaller and lighter than the L298N, which matters for our weight budget.

We considered the DRV8833 (dual-channel, 1.5A/channel) but rejected it because our N20 motors draw up to 1.5A stall each — right at the DRV8833's limit, with no safety margin. The DRV8871's 3.6A headroom is much more comfortable. Each DRV8871 module drives one motor channel (front or rear), with independent forward/backward GPIO pin pairs, and its logic inputs are driven directly from Raspberry Pi GPIO with no separate microcontroller needed.

### Design iteration history

| Version | Key change | Reason / Result |
|---|---|---|
| v1.0 | Off-shelf 4WD chassis, breadboard wiring | Testing baseline — high vibration, unstable sensors |
| v1.1 | Replaced breadboard with soldered protoboard | Eliminated loose-connection faults |
| v2.0 | Custom 3D-printed top plate, camera moved to front | Reduced vibration noise, improved camera FOV |
| v2.1 | Added LIDAR tower mount | LIDAR previously taped to chassis — now rigid and repeatable |
| v3.0 | (Current) Removed ESP32 and ultrasonic sensors, consolidated all control onto the Raspberry Pi via `gpiozero`/`pigpio`, full cable management, dedicated power rails | Simplified wiring, cut cost and weight, eliminated UART maintenance and ground-loop noise from the removed ultrasonic sensors and delete the AWD traction for a RWD|

### Risk analysis

| Risk | Likelihood | Mitigation |
|---|---|---|
| Camera loses detection under venue lighting (Obstacle Challenge) | Low | HSV thresholds recalibrated on-site the day before the event |
| PWM jitter from Python/OS scheduling | Low | `gpiozero`'s `pigpio` pin factory generates pulses via DMA hardware, independent of Python loop timing |
| LiPo battery depleted mid-round | Low | Battery checked at >80% before each round; runtime >> round duration |
| Front-motor wiring present but software-disabled could be flagged at inspection | Medium | Team evaluating physically removing/disconnecting the front motor before finals |
| Fixed-count (11-turn) lap loop rather than start-line detection could mis-navigate on an unexpected track layout | Medium | Practiced against the expected track geometry; a start-line/lap-crossing detector is on our future-work list |
| Close-range blind spot (LIDAR min. range 15cm) | Low | Approach speed reduced near walls; early-exit ("CUELLO") check stops the long wall-follow segment before a too-close approach |

[▲ Menu](#contents)

---

## Robot construction guide

### Component list

| Component | Quantity | Description | Link |
|---|---|---|---|
| Slamtec RPLIDAR A1M8 360° 2D LIDAR Scanner | 1 | 360° LIDAR for wall following and close-range checks | [Amazon](https://www.amazon.com/dp/B07TJW5SXF) |
| N20 DC Gear Motor 12V 400RPM Metal Gearbox | 1 | Rear drive | [Amazon](https://www.amazon.com/dp/B0DB26SYNP) |
| HobbyPark Brass 1.0 Beadlock Wheels & Tires for 1/18 TRX4M | 4 | Brass beadlock wheels + tires + foam inserts | [Amazon](https://www.amazon.com/dp/B0C3MNX4K7) |
| PATIKIL U-Joint Steering Shaft Coupler 4mm to 3mm | 1 | Universal joint connects servo to front axle | [Amazon](https://www.amazon.com/dp/B0FWJGLZ9V) |
| RC Front & Rear Axle Housing Set (TRX4M compatible) | 2 | Ackermann steering linkage | [Amazon](https://www.amazon.com/dp/B0CW2HFT57) |
| Raspberry Pi 4B (4GB) | 1 | Main compute / vision / control unit | [Amazon](https://a.co/d/084kiOZ5) |
| DIYmall 11KG Mini All-Metal Digital Servo (360° Coreless) | 1 | Front-wheel steering | [Amazon](https://www.amazon.com/dp/B0DX1XG18Y) |
| DRV8871 H-Bridge DC Motor Driver | 1 | PWM motor control, 3.6A peak, one per motor channel | [MercadoLibre](https://www.mercadolibre.com.mx/modulo-driver-drv8871-puente-h-control-motor-36a-65v-a-45v/up/MLMU3232504497) |
| Freenove 8MP Camera | 1 | Traffic sign color detection (Obstacle Challenge program) | [Amazon](https://www.amazon.com/dp/B0BZYPBS17) |
| OVONIC 3S 11.1V 2200mAh LiPo Battery | 1 | Main power source | [Amazon](https://www.amazon.com/dp/B0D8SZRGJT) |
| DC-DC Buck Converter 5V 5A | 1 | Steps 11.1V down to 5V rail | [Amazon](https://www.amazon.com/dp/B0D7MR48LB) |
| 3×120 Dupont Jumper Cables 40cm (M-M, M-F, F-F) | 3 packs | Wiring between all modules | [MercadoLibre](https://articulo.mercadolibre.com.mx/MLM-3643032042-3pzs-120-jumper-cable-dupont-wire-40cm-cable-para-protoboard-_JM) |
| Velstron 1,112-piece M3/M4/M5/M6 Screws, Bolts & Nuts Kit | 1 | Chassis fasteners and assembly hardware | [MercadoLibre](https://www.mercadolibre.com.mx/kit-surtido-de-1112-piezas-de-tornillos-pernos-y-tuercas/up/MLMU582984840) |
| 5-Pack Rocker Switch ON/OFF Red 2-Pin 127V/10A | 1 | In-line with battery positive | [MercadoLibre](https://www.mercadolibre.com.mx/5-pzas-interruptor-onoff-rojo-2-pines-127v10a-rojo/p/MLM59606936) |
| GY521 MPU6050 3-axis gyroscope | 1 | Help the robot to know the position of where he is | [AMAZON](https://www.amazon.com/gp/product/B0CRVR1P66/ref=ox_sc_act_title_1?smid=A1MYENKL68XMV9&psc=1). |

**Estimated total cost: ~$325 USD**

### Pre-installation checks

**Servo motor:** Connect to the Raspberry Pi (via `gpiozero`/`pigpio`) and confirm the software `CENTER_OFFSET` trim before mounting. Physical center must match the trimmed electrical center or the robot will always drift to one side.

**DC motors:** Apply 12V directly and confirm rotation direction matches expected forward for both the rear (active) and front (currently disabled) channels. The red terminal dot indicates positive.

### Electrical wiring — servo motor

| Wire color | Function |
|---|---|
| Brown | GND |
| Red | VCC (5V) |
| Yellow | PWM signal from Raspberry Pi GPIO 12 (`gpiozero`/`pigpio`) |

### Electrical wiring — motor drivers (as implemented)

| GPIO pin | Function |
|---|---|
| 23 | Rear motor DRV8871 IN1 (forward) — active |
| 22 | Rear motor DRV8871 IN2 (backward) — active |
| 12 | Servo PWM signal |

**Power switch:** Wired in series with the battery positive lead. Always switch off when not in use to protect the LiPo.

### Safety notes

- Do not operate in humid environments
- Verify polarity before connecting battery
- Never short the LiPo terminals — use a fused connector
- Double-check all wiring before first power-on after any reassembly

### Board mounting

The 3D-printed top plate has mounting holes for:
- Raspberry Pi 4B (standard 58mm hole spacing)
- Camera bracket (front-center)
- LIDAR tower (center, elevated ~60mm above chassis)

For all 3D files: [📁 Models](./models/)

[▲ Menu](#contents)

---

## Engineering materials

This repository contains all engineering materials for Team CICSA's self-driving vehicle competing in WRO Future Engineers 2026.

| Quantity | Component | Link |
|---|---|---|
| 1 | Raspberry Pi 4B (4GB) — ~$55 | [Amazon](https://a.co/d/084kiOZ5) |
| 1 | Freenove 8MP Camera — ~$14 | [Amazon](https://www.amazon.com/dp/B0BZYPBS17) |
| 1 | DRV8871 H-Bridge DC Motor Driver — ~$4 | [MercadoLibre](https://www.mercadolibre.com.mx/modulo-driver-drv8871-puente-h-control-motor-36a-65v-a-45v/up/MLMU3232504497) |
| 1 | Slamtec RPLIDAR A1M8 360° 2D LIDAR — ~$99 | [Amazon](https://www.amazon.com/dp/B07TJW5SXF) |
| 1 | N20 DC Gear Motor 12V 400RPM — ~$8 | [Amazon](https://www.amazon.com/dp/B0DB26SYNP) |
| 1 | DIYmall 11KG Mini All-Metal Digital Servo — ~$16 | [Amazon](https://www.amazon.com/dp/B0DX1XG18Y) |
| 4 | HobbyPark Brass Beadlock Wheels & Tires 1/18 TRX4M — ~$20/set | [Amazon](https://www.amazon.com/dp/B0C3MNX4K7) |
| 1 | PATIKIL U-Joint Steering Shaft Coupler 4mm→3mm — ~$8 | [Amazon](https://www.amazon.com/dp/B0FWJGLZ9V) |
| 2 | RC Front & Rear Axle Housing Set (TRX4M) — ~$12 | [Amazon](https://www.amazon.com/dp/B0CW2HFT57) |
| 1 | OVONIC 3S 11.1V 2200mAh LiPo Battery — ~$25 | [Amazon](https://www.amazon.com/dp/B0D8SZRGJT) |
| 1 | DC-DC Buck Converter 5V 5A — ~$10 | [Amazon](https://www.amazon.com/dp/B0D7MR48LB) |
| 3 packs | 3×120 Dupont Jumper Cables 40cm — ~$6/pack | [MercadoLibre](https://articulo.mercadolibre.com.mx/MLM-3643032042-3pzs-120-jumper-cable-dupont-wire-40cm-cable-para-protoboard-_JM) |
| 1 | Velstron 1,112-piece M3/M4/M5/M6 Hardware Kit — ~$18 | [MercadoLibre](https://www.mercadolibre.com.mx/kit-surtido-de-1112-piezas-de-tornillos-pernos-y-tuercas/up/MLMU582984840) |
| 1 | 5-Pack Rocker Switch ON/OFF Red 2-Pin 127V/10A — ~$4 | [MercadoLibre](https://www.mercadolibre.com.mx/5-pzas-interruptor-onoff-rojo-2-pines-127v10a-rojo/p/MLM59606936) |
| 1 | GY521 MPU6050 3-axis gyroscope - ~$4 | [AMAZON](https://www.amazon.com/gp/product/B0CRVR1P66/ref=ox_sc_act_title_1?smid=A1MYENKL68XMV9&psc=1). |

**Estimated total cost: ~$375 USD**

### Component function summary

| Component | Function |
|---|---|
| Raspberry Pi 4B | State machine, LIDAR processing, PID control, and PWM output (via `gpiozero`/`pigpio`) — all navigation logic in one controller |
| Freenove Camera | Traffic sign color detection via OpenCV (Obstacle Challenge program only) |
| Slamtec RPLIDAR A1M8 | 360° sector-based wall distance mapping for navigation and direction detection |
| DRV8871 Driver | Efficient H-bridge motor control, driven directly from Pi GPIO |
| N20 DC Gear Motor| Rear-wheel drive active |
| DIYmall 11KG Servo | Front-wheel Ackermann steering, driven via `gpiozero`'s `AngularServo` (pigpio-backed) |
| HobbyPark Brass Wheels (×4) | High-grip 1.0" beadlock wheels for 1/18 TRX4M chassis |
| PATIKIL U-Joint Coupler | 4mm-to-3mm universal joint connecting servo shaft to front axle |
| RC Front & Rear Axle Set | Steering axle housings |
| OVONIC 3S 2200mAh LiPo | Main power (11.1V, ~55 min runtime) |
| Buck Converter 5V | Regulated 5V rail for Pi, LIDAR, servo |
| Dupont Jumper Cables | All inter-module wiring connections |
| M3/M4/M5/M6 Hardware Kit | Chassis assembly fasteners (screws, bolts, nuts, washers) |
| Rocker Switch ON/OFF Red 2-Pin | Power control switch in-line with battery positive |
| GY521 MPU6050 3-axis gyroscope | Know the robot position at all time |

### Software and libraries

| Platform | Language | Libraries | Role |
|---|---|---|---|
| Raspberry Pi 4B | Python 3 | `rplidar` | LIDAR scan parsing |
| | | `gpiozero` (pigpio pin factory) | Hardware-timed motor and servo control |
| | | `numpy`, `scipy.ndimage` | LIDAR DSP: interpolation, median filtering, gradient checks |
| | | Custom velocity-form PID | Wall-following steering control |
| | | OpenCV | Color detection, contour analysis — Obstacle Challenge program only |

[▲ Menu](#contents)

---

## Performance videos

> Video links are documented in [📁 Video](./video/video.md).

- Open Challenge — practice run (3 laps complete)
- Obstacle Challenge — practice run (3 laps + parking)
- Robot assembly time-lapse

[▲ Menu](#contents)

---

## Final remarks and future work

We are proud of how Team CICSA's robot evolved over this season. Starting from a vibration-prone breadboard prototype, we arrived at a stable, reproducible platform with clean cable routing, rigid sensor mounting, and a well-tuned PID controller. Consolidating everything onto a single Raspberry Pi — with `gpiozero`'s pigpio-backed PWM handling hardware timing — let us simplify our wiring and cut both cost and weight versus our previous ESP32 + ultrasonic setup, and we would recommend this simplified architecture to future teams building at a similar drive speed.

**What worked well:**
- The LIDAR-based wall following is robust to lighting changes and requires no floor markings
- The DSP pipeline (interpolation + median filter + gradient rejection) meaningfully cleaned up noisy LIDAR sectors before they reached the PID loop
- `gpiozero`'s pigpio pin factory kept servo and motor pulses stable even without a dedicated microcontroller

**What we would improve with more time:**
- Replace the fixed 11-turn loop with actual start/finish-line detection so lap counting is robust to any track layout, not just the practiced one
- Finalize the drivetrain as a true single-motor build (physically, not just via software flag) to remove any ambiguity around the single-drive-axle rule
- Implement a Kalman filter to fuse LIDAR and camera-derived distance estimates for more accurate position estimation
- Add an IMU (MPU6050) to detect and correct for wheel slip during sharp corners
- Improve the parking algorithm to use pixel-level magenta zone detection rather than distance-based thresholding
- Add a web dashboard on the Pi for real-time parameter tuning over Wi-Fi during practice sessions

We thank Coach Sergio Iván for his support and guidance throughout the season, and CICSA Academy for providing the resources and space to build and test our robot.

[▲ Menu](#contents)

- This is a small circuit made in Proteus showing the wiring layout described above. We didn't have every exact part on hand for the simulation, so some components are represented with similar substitute parts under different labels.



---

## References

1. WRO 2026 Future Engineers General Rules — https://wro-association.org/wp-content/uploads/WRO-2026-Future-Engineers-Self-Driving-Cars-General-Rules.pdf
2. WRO 2026 Documentation Rubric — https://wro-association.org/wp-content/uploads/WRO-2026-Future-Engineers-Documentation-Rubric.pdf
3. RPLidar A1M8 SDK — https://github.com/Slamtec/rplidar_sdk
4. OpenCV HSV color detection — https://docs.opencv.org/4.x/df/d9d/tutorial_py_colorspaces.html
5. Ziegler–Nichols PID tuning method — Ziegler, J.G. & Nichols, N.B. (1942). *Transactions of the ASME*, 64, 759–768.
6. gpiozero documentation — https://gpiozero.readthedocs.io/
7. pigpio library documentation — https://abyz.me.uk/rpi/pigpio/
8. WRO Future Engineers Getting Started Guide — https://world-robot-olympiad-association.github.io/future-engineers-gs/

[▲ Menu](#contents)

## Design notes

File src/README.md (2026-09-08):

Control software
====

This directory must contain code for control software which is used by the vehicle to participate in the competition and which was developed by the participants.

All artifacts required to resolve dependencies and build the project must be included in this directory as well.

# Main 26_05_26

## PID Wall-Following Robot

This repository contains the first version of a MicroPython program for a mobile robot that maintains a reference distance from a side wall.

The system uses an ultrasonic sensor to measure the distance on the left side. A PID controller processes this measurement and changes the steering servo angle while the robot moves forward.

## Project Status

This is the *first experimental version*. Its main purpose is to test:

- Continuous ultrasonic distance measurement.
- Steering servo control.
- Motor movement using PWM.
- Trajectory correction using a PID controller.

The PID constants and servo limits still require physical calibration on the robot.

## Hardware

- Microcontroller compatible with MicroPython.
- Side-mounted ultrasonic sensor.
- SG90 servo motor for steering.
- DC motor or motors.
- Motor driver compatible with PWM signals.
- Suitable power supply for the motors, servo, and microcontroller.

## Pin Connections

| Component | Signal | GPIO |
|---|---|---:|
| LED | Output | 2 |
| Left ultrasonic sensor | TRIG | 4 |
| Left ultrasonic sensor | ECHO | 15 |
| SG90 servo motor | PWM | 21 |
| Motor driver | RPWM | 23 |
| Motor driver | LPWM | 22 |

> *Important:* all modules must share a common ground. Verify that the ultrasonic sensor's ECHO voltage is safe for the microcontroller. Do not power the motor or servo directly from a GPIO pin.

## How It Works

1. The LED turns on briefly to indicate that the program has started.
2. A second thread continuously reads the left ultrasonic sensor.
3. The robot begins moving forward at a constant PWM value.
4. The controller compares the measured distance with the reference distance.
5. The PID controller processes the resulting error.
6. The PID output changes the steering servo angle.
7. The motor stops after the configured number of control iterations.

## PID Controller

The current reference distance is *15 cm*. The initial controller values are:

| Constant | Value |
|---|---:|
| Kp | 6 |
| Ki | 0.02 |
| Kd | 2.6 |

The calculated steering angle is limited between *45° and 105°, with **70°* used as the initial center position.

The main function call used in this version is:

python
pid(15, 600, 10000)

The arguments represent:

- 15: reference distance in centimeters.
- 600: number of control iterations.
- 10000: PWM value used for forward movement.

## Software Requirements

- MicroPython firmware installed on the microcontroller.
- Thonny, mpremote, or another compatible tool for uploading and running the program.
- No external libraries are required.

## Running the Program

1. Connect all components according to the pin table.
2. Save the main program as main.py on the microcontroller.
3. Place the robot on a safe surface with enough room to move.
4. Turn on the system and observe the measurements displayed in the console.
5. Adjust Kp, Ki, Kd, the center angle, and the speed according to the robot's physical response.

The console displays information similar to:

text
Distance: 15 PID Output: 0.0 Angle: 70

## Main Program Structure

- forward(value): controls forward movement using PWM.
- set_servo_angle(angle): converts an angle from 0° to 180° into a PWM signal for the servo.
- get_distance(echo, trig): obtains a measurement from the ultrasonic sensor.
- get_data(): continuously updates the distance in a second thread.
- pid(ref, condition, speed): executes the trajectory controller.

## Planned Improvements

- Correct and validate the ultrasonic trigger pulse.
- Handle invalid measurements or None values without stopping the program.
- Filter unstable sensor measurements.
- Calculate the PID controller using a real sampling interval.
- Add limits to the accumulated output to prevent saturation.
- Add an emergency stop.
- Organize the program into separate modules.
- Document the exact microcontroller and motor-driver models.

## Testing Safety

Perform the first tests with the wheels raised or at low speed. Keep the movement area clear and use an appropriate power supply to prevent resets or damage to the electronic components.

## License

This project is published for educational and experimental development purposes. A formal license may be added in a future version.

# wro2026_obstacle.py

## WRO 2026 Future Engineers - Obstacle Challenge

Autonomous vehicle developed for the *WRO 2026 Future Engineers Obstacle Challenge*. The system runs on a Raspberry Pi 4 and combines a 2D LiDAR, a camera, and an MPU6050 inertial sensor to follow walls, determine the driving direction, avoid colored traffic pillars, negotiate corners, recover from critical situations, and complete the required laps.
 
> Main program: wro2026_obstacle.py

## Project goals

The controller was designed around five priorities:

- Compliance with the WRO Future Engineers obstacle rules.
- Repeatable behavior with different battery levels.
- Sensor validation instead of acting on isolated measurements.
- A clear finite-state machine for testing and debugging.
- Recovery from temporary faults without immediately ending the run.

## Hardware

| Component | Purpose | Connection |
|---|---|---|
| Raspberry Pi 4 | Main computer and control coordinator | Central controller |
| RPLidar A1 | Front and lateral distances, wall geometry, open spaces, and corner detection | USB serial, normally /dev/ttyUSB0 |
| Freenove IMX219 camera | Red/green pillar detection and image position | Raspberry Pi CSI interface |
| MPU6050 | Angular velocity, accumulated heading, and 90-degree turn confirmation | I2C: SDA GPIO 2, SCL GPIO 3 |
| Ackermann steering servo | Front steering angle | GPIO 12 |
| Rear DC motor and driver | Forward and reverse movement | GPIO 23 and GPIO 22 |

The LiDAR convention used by the software is:

- 0°: front
- 90°: right
- 180°: rear
- 270°: left

Positive steering angles turn left; negative angles turn right.

## System architecture

The sensors run in independent background threads. Each thread publishes its newest measurement with a sequence number and timestamp. A single fixed-rate controller reads the latest snapshots at *40 Hz*, validates them, executes the active state, and sends commands to the steering servo and rear motor.

mermaid
flowchart TD
    CAM["Camera<br/>pillar color, x, bottom, area"]
    LIDAR["RPLidar A1<br/>front, left, right, wall angle"]
    MPU["MPU6050<br/>heading and angular change"]

    SNAP["Time-stamped sensor snapshots"]
    VALID["Validation and filtering"]
    FSM["40 Hz finite-state controller"]
    ACT["Steering servo and rear motor"]
    TELE["CSV telemetry"]

    CAM --> SNAP
    LIDAR --> SNAP
    MPU --> SNAP
    SNAP --> VALID --> FSM
    FSM --> ACT
    FSM --> TELE

## How each sensor is used

### RPLidar A1

The LiDAR is the main geometric sensor. Its scans are divided into angular sectors to obtain front, left, and right distances. Recent measurements are filtered with medians and checked for minimum point count, age, physical range, and impossible jumps.

It supports:

- Corridor centering before the driving direction is known.
- Outer-wall following during normal sections.
- Selection of the closest reliable wall during pillar avoidance.
- Detection of the front wall before a corner.
- Verification that enough space exists during reverse and corner exit.
- Recovery when a distance becomes critical or the LiDAR stops updating.

### Camera

The IMX219 camera detects red and green traffic pillars. The image pipeline applies a region of interest, color segmentation, blob filtering, and geometric plausibility checks.

For every candidate, the controller considers:

- Color: red or green.
- Horizontal position (x).
- Bottom position in the image.
- Blob area and shape.
- Agreement between two independent distance estimates.

The color determines the legal passing side:

| Pillar | Robot passes on | Pillar remains on |
|---|---|---|
| Red | Right | Left side of the robot |
| Green | Left | Right side of the robot |

A short hold period prevents the maneuver from ending because of one missed camera frame. After the pillar disappears, the controller completes the crossing using LiDAR distance and MPU6050 heading.

### MPU6050

The MPU6050 is calibrated while the robot is completely stationary. The Z-axis gyroscope is filtered and integrated to estimate accumulated heading.

It is used to:

- Maintain a heading reference during cascaded wall control.
- Measure the angular displacement produced while avoiding a pillar.
- Apply counter-steering after the pillar has been passed.
- Confirm each 90-degree corner by heading instead of time alone.
- Compare the expected total heading with the number of completed corners.

Using heading feedback makes the corner maneuver less dependent on motor speed or battery voltage.

## Finite-state machine

mermaid
stateDiagram-v2
    [*] --> START
    START --> DETERMINE_DIRECTION: sensors ready
    DETERMINE_DIRECTION --> REVERSE: first corner detected

    STRAIGHT --> PILLAR: valid pillar detected
    PILLAR --> STRAIGHT: pillar passed
    STRAIGHT --> REVERSE: corner confirmed

    REVERSE --> TURN: reverse clearance reached
    TURN --> EXIT_TURN: 90-degree turn confirmed
    EXIT_TURN --> STRAIGHT: more corners required
    EXIT_TURN --> FINISHED: final corner completed

    DETERMINE_DIRECTION --> RECOVER: recoverable condition
    STRAIGHT --> RECOVER: recoverable condition
    PILLAR --> RECOVER: recoverable condition
    REVERSE --> RECOVER: recoverable condition
    TURN --> RECOVER: recoverable condition
    EXIT_TURN --> RECOVER: recoverable condition
    RECOVER --> DETERMINE_DIRECTION: retry initial approach
    RECOVER --> STRAIGHT: retry section
    RECOVER --> REVERSE: retry corner
    FINISHED --> [*]

| State | Main responsibility | Principal sensors |
|---|---|---|
| START | Initialize actuators, telemetry, and sensor threads | All |
| DETERMINE_DIRECTION | Center the robot and identify the outer wall at the first corner | LiDAR, camera, MPU6050 |
| STRAIGHT | Follow the active reference wall and search for the next event | LiDAR, camera, MPU6050 |
| PILLAR | Cross to the legal side and pass the detected pillar | Camera, LiDAR, MPU6050 |
| REVERSE | Create enough space before turning | LiDAR |
| TURN | Execute and confirm the 90-degree corner | MPU6050, LiDAR fallback |
| EXIT_TURN | Leave the corner and restore normal motion | LiDAR |
| RECOVER | Reverse, reposition, and retry a recoverable state | LiDAR, active-state context |
| FINISHED | Stop motion, close telemetry, and stop threads | All |

## Development process

### 1. Basic propulsion and steering

Development started by calibrating the rear motor, steering center, and asymmetric left/right steering limits. Braking was improved with a short opposite-direction motor pulse to reduce inertia and make stopping distance more repeatable.

### 2. LiDAR wall following

The first autonomous behavior used the RPLidar A1 to follow the outer wall. Raw scans were divided into sectors and filtered. A fixed-rate loop was then introduced so control timing no longer depended on the LiDAR scan rate.

The straight controller evolved into a cascaded structure:

1. Lateral distance error generates a target heading offset.
2. MPU6050 heading error generates the steering command.
3. Steering limits and critical-distance protections constrain the result.

### 3. Camera-based pillar detection

Red and green segmentation was added using the Raspberry Pi camera. Early tests showed that color alone could create false detections, so the detector was expanded with minimum area, aspect ratio, bounding-box fill, region-of-interest, temporal confirmation, and geometric plausibility filters.

Two image measurements estimate pillar distance independently: blob area and vertical bottom position. A candidate is accepted only when both estimates are reasonably consistent.

### 4. Pillar avoidance

The first avoidance controller always referenced the outer wall. That became unreliable when the robot crossed away from it, especially when a black wall produced few LiDAR returns at long range.

The final strategy follows one rule: *during avoidance, use the wall on the side toward which the robot is crossing*. This keeps the reference wall closer and gives the LiDAR a more reliable surface.

The maneuver continues briefly after the camera loses sight of the pillar. LiDAR distance controls the remaining lateral crossing, while the MPU6050 measures the heading change and guides the counter-steering phase.

### 5. MPU6050 heading control

Time-based turns varied with battery voltage and surface conditions. The MPU6050 was therefore added to measure heading directly. The software calibrates gyroscope bias at startup, filters vibration, learns or applies the rotation sign, and confirms the corner when the accumulated change reaches the target angle.

### 6. Recovery and robustness

Instead of aborting after every sensor anomaly, the controller classifies selected faults as recoverable. Recovery brakes the robot, chooses a safe reverse steering direction from the obstacle location, reverses until space is available, centers the steering, and retries the interrupted state.

Additional protections include:

- Sensor age and health checks.
- LiDAR jump rejection held for the complete scan.
- Maximum valid wall distance.
- Critical front and lateral distances.
- Camera outage speed limitation.
- Maximum duration for blind crossing phases.
- Limited recovery and corner retry counts.
- CSV telemetry for post-run analysis.

### 7. Direction detection and complete-lap sequence

At startup, the robot does not yet know which wall is outside. It centers between both walls and approaches the first corner. The side that opens identifies the inner area of the track; the opposite side becomes the outer reference wall. The controller then executes the first corner and repeats straight-section and corner states until the configured number of corners is complete.

## Software requirements

- Raspberry Pi OS with Python 3
- gpiozero
- pigpio daemon and Python interface
- opencv-python / Raspberry Pi OpenCV package
- picamera2
- smbus2
- rplidar (rplidar-roboticia compatible API)

## Running the controller

Start the pigpio service before a hardware run:

bash
sudo systemctl start pigpiod

Run a normal three-lap session:

bash
cd /home/pi/wro2026/wro2026_obstacle
source /home/pi/rplidar_env/bin/activate
python3 wro2026_obstacle_english.py

Run one lap for testing:

bash
python3 wro2026_obstacle_english.py --vueltas 1

Run the logic tests without hardware:

bash
python3 wro2026_obstacle_english.py --autotest

Run the simulator when the companion simulation module is available:

bash
python3 wro2026_obstacle_english.py --sim

Disable telemetry if required:

bash
python3 wro2026_obstacle_english.py --sin-telemetria

> Keep the robot completely still during MPU6050 calibration. For bench testing, raise the driven wheels or disconnect motor power until the steering and sensor checks are complete.

## Telemetry

During a run, the controller can save CSV rows containing:

- Current state and corner number.
- Front, left, and right LiDAR distances.
- Active reference wall and target distance.
- Steering and speed commands.
- Pillar color, horizontal position, bottom position, and area.
- MPU6050 heading and relative heading.
- LiDAR and camera health flags.

These logs were essential for comparing runs, identifying false measurements, adjusting thresholds, and verifying whether a failure came from perception, control, or mechanical behavior.

## Repository structure

text
.
├── README.md
├── wro2026_obstacle_english.py   # Main controller
├── simulacion.py                 # Optional hardware simulator
├── diagrams/
│   ├── flowchart.png
│   └── state_machine.png
└── telemetry/                    # CSV run logs (normally ignored by Git)

The main controller currently imports the optional simulator as simulacion.py. If the file is renamed, update the import in the controller at the same time.

# wro2026_open.py

## Autonomous LiDAR Wall-Following Robot

First version of an autonomous mobile robot controller developed in Python for Raspberry Pi. The robot uses an RPLidar sensor to detect surrounding walls, selects a navigation direction automatically, follows a reference wall with PID steering control, and performs open-loop 90-degree corner maneuvers.

## Project Status

This is validate the main navigation architecture:

- Continuous LiDAR acquisition in a background thread.
- Front, left, and right region-of-interest processing.
- Wall-following control using a discrete PID controller.
- Median-based steering-output filtering.
- Automatic initial direction selection.
- Steering-servo control with mechanical limits.
- Front and rear drivetrain control.
- Automatic corner detection and turning.
- Safe actuator shutdown when the program ends.

## System Overview

The software is divided into four main layers:

1. *Perception:* reads RPLidar scans and separates measurements into front, left, and right zones.
2. *Filtering:* rejects low-quality, out-of-range, and discontinuous measurements.
3. *Control:* calculates a steering correction using a discrete PID controller.
4. *Actuation:* commands the steering servo and the front/rear motors.

## Hardware

- Raspberry Pi 4.
- RPLidar connected through USB.
- Steering servomotor.
- Front DC motor or front axle motor group.
- Rear DC motor or rear axle motor group.
- Two DRV8871 H-bridge motor drivers.
- Independent and properly regulated power supply for the motors and servo.
- Common ground between the Raspberry Pi and motor/servo electronics.

## GPIO Connections

The program uses BCM GPIO numbering.

| Subsystem | Signal | BCM GPIO |
|---|---|---:|
| Front motor driver | IN1 | 17 |
| Front motor driver | IN2 | 18 |
| Rear motor driver | IN1 | 23 |
| Rear motor driver | IN2 | 22 |
| Steering servo | PWM signal | 12 |

The RPLidar serial port is configured as:

text
/dev/ttyUSB0

> Verify the GPIO wiring and voltage levels before powering the robot. Do not power the motors or steering servo directly from the Raspberry Pi GPIO header.

## Software Requirements

- Raspberry Pi OS.
- Python 3.
- A running pigpio daemon.
- RPLidar Python driver.
- GPIO Zero.
- NumPy.
- SciPy.

The project uses the following Python imports:

python
from rplidar import RPLidar
from gpiozero import Motor, AngularServo
import numpy as np
from scipy.ndimage import median_filter

## Python Environment

For the current Raspberry Pi setup, the RPLidar virtual environment is located at:

bash
/home/pi/rplidar_env

Activate it before running the program:

bash
source /home/pi/rplidar_env/bin/activate

Start the pigpio service:

bash
sudo systemctl start pigpiod

You can verify its status with:

bash
sudo systemctl status pigpiod

## Running the Program

1. Connect the RPLidar, steering servo, and motor drivers.
2. Place the robot in a safe test area with the wheels raised for the first test.
3. Start the pigpio daemon.
4. Activate the RPLidar virtual environment.
5. Run the Python file:

bash
cd /path/to/project
source /home/pi/rplidar_env/bin/activate
python3 main.py

Replace main.py with the actual filename if necessary.

Stop the program with Ctrl+C. The shutdown routine stops both motors and returns the steering command to its center position.

## LiDAR Regions of Interest

The point cloud is divided into three angular zones:

| Region | Minimum angle | Maximum angle |
|---|---:|---:|
| Front | -5° | 5° |
| Left | 255° | 285° |
| Right | 75° | 105° |

Only samples with a quality value of at least 5 and a nonzero distance are processed.

## LiDAR Filtering

Each region passes through a filtering pipeline:

1. Sort points by angle.
2. Reject distances outside the configured range.
3. Interpolate invalid samples.
4. Apply a median filter.
5. Reject abrupt distance discontinuities.
6. Select the nearest valid obstacle in each region.

Default filtering parameters:

| Parameter | Value |
|---|---:|
| Minimum distance | 150 mm |
| Maximum distance | 6000 mm |
| Median window | 3 samples |
| Step threshold | 500 mm |

## Steering Configuration

The steering convention is:

- 0°: straight.
- Positive angle: left turn.
- Negative angle: right turn.

Current calibration values:

| Parameter | Value |
|---|---:|
| Mechanical center offset | -20° |
| Maximum steering command | ±40° |
| Servo pulse-width range | 0.5–2.5 ms |

The requested steering command is constrained before the mechanical offset is applied.

## Drivetrain Configuration

The base velocity is:

python
target_velocity = 0.5

Front and rear power can be calibrated independently:

python
FACTOR_FRONT = 1.00
FACTOR_REAR = 1.00

The front axle is currently controlled by:

python
MOTOR_FRONT_FLAG = False

With this value, only the rear motor is actively commanded. Change it to True only after verifying the front motor direction and drivetrain behavior.

## PID Wall Following

The robot follows either the left or right wall at a reference distance of:

text
300 mm

Current PID settings:

| Parameter | Value |
|---|---:|
| Kp | 1.2 |
| Ki | 0.0 |
| Kd | 0.5 |
| Sample period | 0.005 s |
| Steering-output limit | ±40° |

The controller uses the selected wall to determine the error sign:

- IZQUIERDA: follow the left wall.
- DERECHA: follow the right wall.

A five-sample history buffer suppresses sudden steering changes. If a new command differs from the recent median by more than 15°, the median value is used instead.

## Automatic Start Sequence

At startup, the robot moves forward slowly while examining both sides:

- If the left opening is greater than 1000 mm and the front wall is at or below 750 mm, the robot turns left and begins following the right wall.
- If the right opening is greater than 1000 mm and the front wall is at or below 750 mm, the robot turns right and begins following the left wall.

## Corner Detection and Turning

During the main wall-following segment, a corner condition is detected when:

- The front distance is at or below 725 mm.
- More than 250 control cycles have elapsed.
- The active segment was configured for 10000 cycles.

The corner label CUELLO is added to the telemetry list, and the controller exits the current straight segment.

The robot then executes a 90-degree turn using:

- Maximum steering angle: 40°.
- Open-loop turn duration: 0.95 s.

These values must be calibrated on the actual surface, battery level, speed, and steering geometry.

## Main Navigation Sequence

The current main routine:

1. Initializes the actuators.
2. Starts the asynchronous LiDAR worker.
3. Waits six seconds for scan stabilization.
4. Determines the initial direction.
5. Repeats wall following and corner turning for 11 segments.
6. Executes a final 300-cycle wall-following segment.
7. Stops the drivetrain and centers the steering during shutdown.

## Main Functions

| Function | Purpose |
|---|---|
| set_steering_angle() | Constrains and applies the steering command |
| drive_forward_awd() | Drives the enabled axles forward |
| drive_backward_awd() | Drives the enabled axles backward |
| stop_awd() | Stops both motors |
| filter_lidar_zone() | Filters one LiDAR region |
| lidar_worker_thread() | Reads and processes LiDAR scans asynchronously |
| sanitize_control_signal() | Rejects sudden steering-output changes |
| pid_wall_follower() | Performs closed-loop wall following |
| execute_start_sequence() | Selects the initial navigation direction |
| execute_90deg_left_turn() | Performs an open-loop left turn |
| execute_90deg_right_turn() | Performs an open-loop right turn |
| initialize_system() | Sets safe initial actuator states |
| terminate_system() | Stops and centers all actuators |

## Known Limitations

- The program assumes that valid LiDAR values are available before every comparison.
- Missing side or front readings may produce runtime errors.
- The LiDAR recovery loop does not currently recreate the sensor object after every failure.
- Turns are time-based rather than closed-loop.
- The telemetry list is stored in memory but is not exported.
- The declared sample period may differ from the real execution period.
- The program does not yet include a physical start button.
- The front axle is disabled by default.
- Competition-specific start, lap-counting, parking, and fail-safe requirements still need validation.

## Planned Improvements

- Add explicit handling for missing or stale LiDAR measurements.
- Reconnect the RPLidar automatically after communication failures.
- Use monotonic timing for the PID loop.
- Implement anti-windup and measured-time PID calculations.
- Replace time-based turns with sensor- or IMU-assisted control.
- Save telemetry to a CSV file.
- Add a physical start button and competition start delay.
- Add watchdog and emergency-stop behavior.
- Divide perception, control, hardware, and main logic into separate modules.
- Add repeatable calibration and validation procedures.

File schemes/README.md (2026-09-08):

Electromechanical diagrams
====

This directory contain schematic diagrams of the electromechanical components illustrating all the elements (electronic components and motors) used in the vehicle and how they connect to each other.

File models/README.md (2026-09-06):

# WRO 2026 Future Engineers - Custom 3D-Printed Robot Parts

## Overview

This document presents the custom mechanical parts designed for our robot for the **WRO 2026 Future Engineers** competition. All models shown below were created by our team and manufactured using 3D printing.

The design is divided into modular bases and supports so that the robot's mechanical and electronic components can be mounted securely and organized clearly.

## Component Summary

| File name | Component | Main function |
|---|---|---|
| `b_principal` | Main chassis | Supports the drivetrain, steering system, LiDAR, and battery |
| `b_battery` | Battery mount | Secures the battery to the main chassis |
| `b_camera` | Camera mount | Supports and positions the camera |
| `b_connector` | Connector base | Provides a mounting surface for the electronic components and connections |
| `b_raspberry` | Raspberry Pi base | Holds the Raspberry Pi 4 main controller |
| `b_servo` | Steering servo mount | Holds the steering servomotor at the front of the robot |
| `s_b_connector` | Connector-base support | Supports the connector base within the robot assembly |

## Mechanical Parts

### 1. Main Chassis - `b_principal`

The main chassis is the robot's central structural component. It provides mounting points for the motor, motor driver, steering axles, steering servomotor, LiDAR, and battery.

| 3D model | Technical drawing |
|---|---|
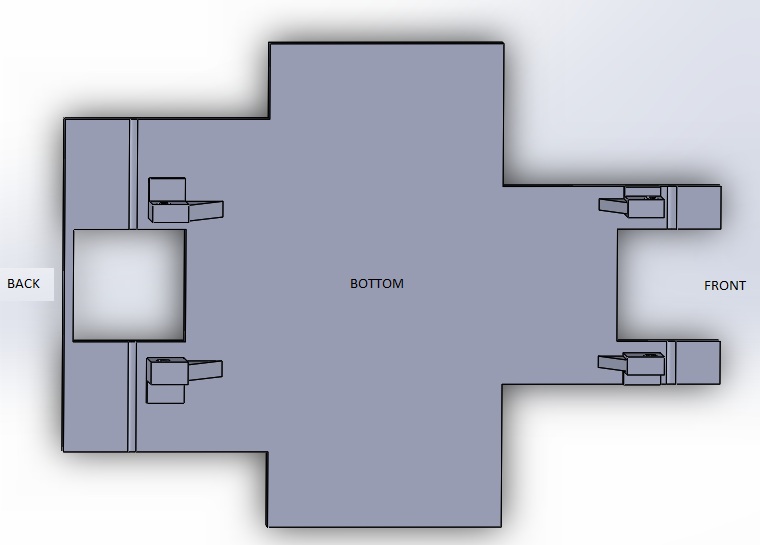
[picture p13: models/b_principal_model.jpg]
3D model of the main robot chassis
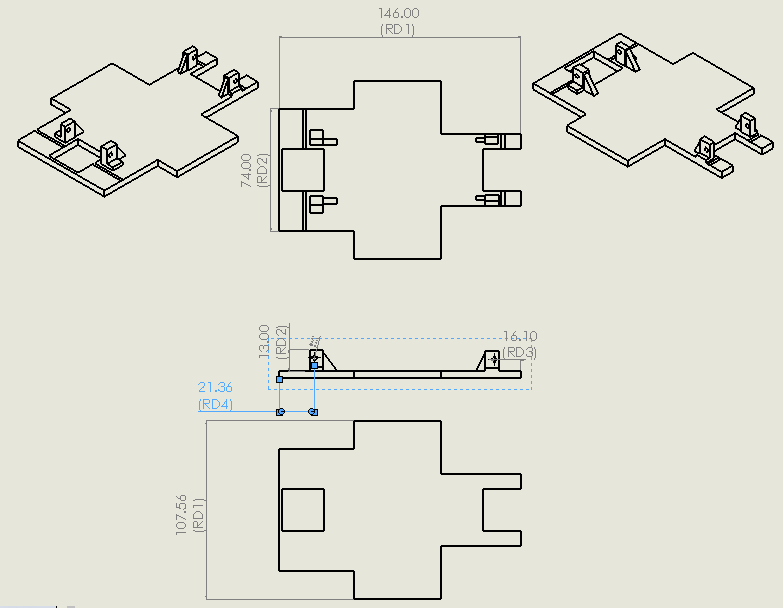
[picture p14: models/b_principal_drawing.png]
Technical drawing of the main robot chassis
|  |  |

### 2. Battery Mount - `b_battery`

This compact base secures the battery and is mounted directly onto the main chassis.

| 3D model | Technical drawing |
|---|---|
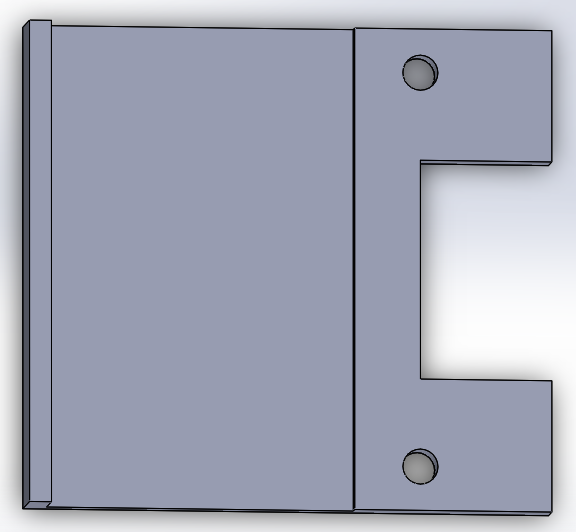
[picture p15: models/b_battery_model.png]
3D model of the battery mount
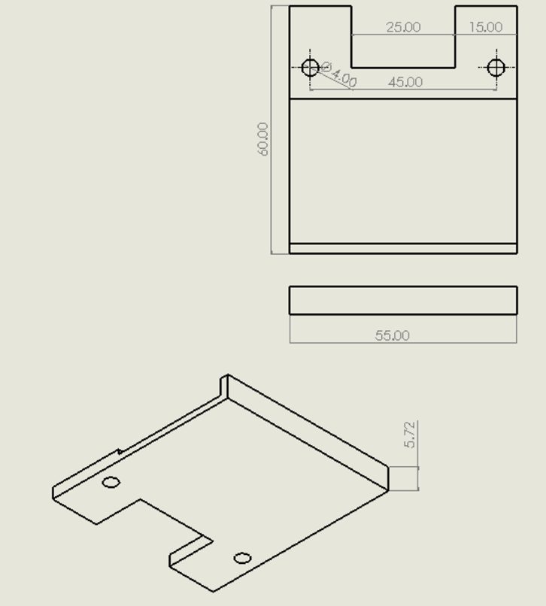
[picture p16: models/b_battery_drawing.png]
Technical drawing of the battery mount
|  |  |

### 3. Camera Mount - `b_camera`

This bracket supports the robot's camera and keeps it in the required position.

| 3D model | Technical drawing |
|---|---|
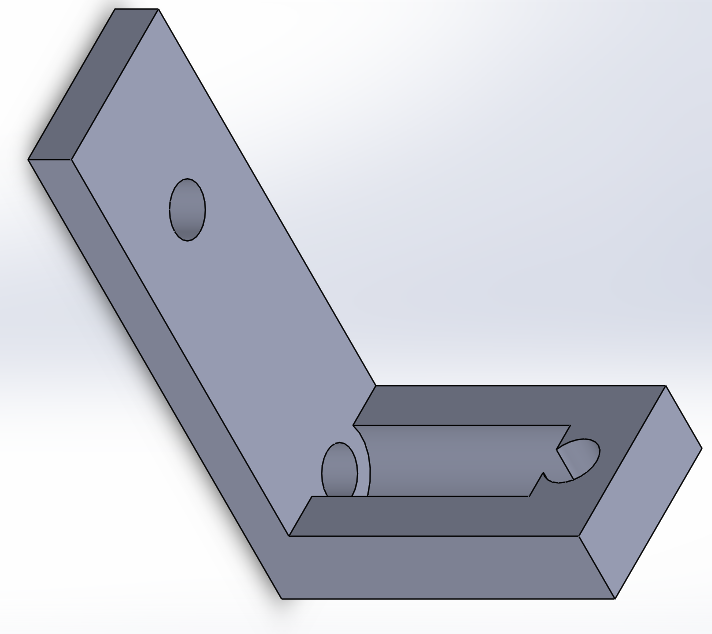
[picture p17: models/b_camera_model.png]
3D model of the camera mount
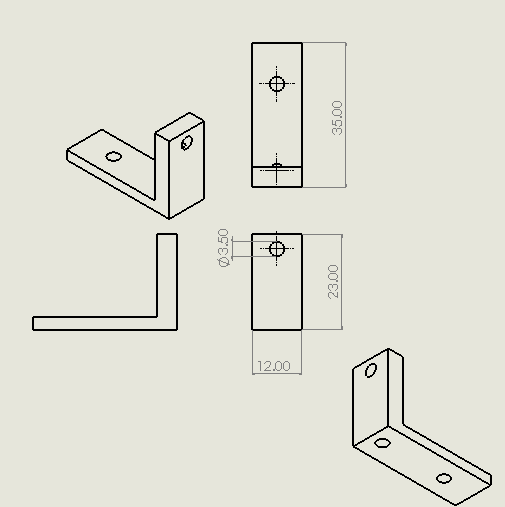
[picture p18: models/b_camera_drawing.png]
Technical drawing of the camera mount
|  |  |

### 4. Connector Base - `b_connector`

This base provides the mounting area for the robot's electronic components and their connections.

| 3D model | Technical drawing |
|---|---|
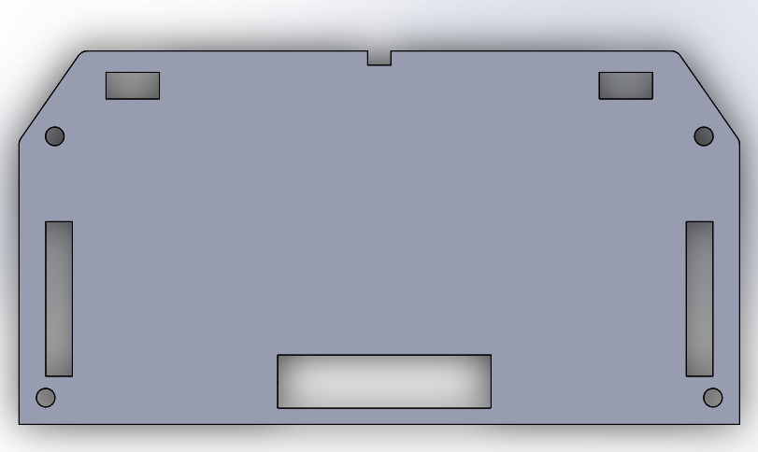
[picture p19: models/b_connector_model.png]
3D model of the connector base
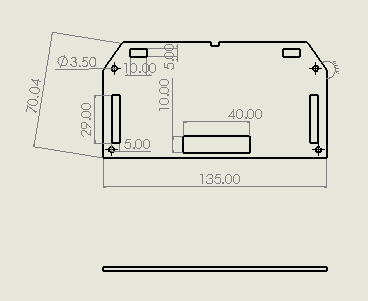
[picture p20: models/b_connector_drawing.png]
Technical drawing of the connector base
|  |  |

### 5. Raspberry Pi Base - `b_raspberry`

This base holds the robot's main processing board, a Raspberry Pi 4.

| 3D model | Technical drawing |
|---|---|
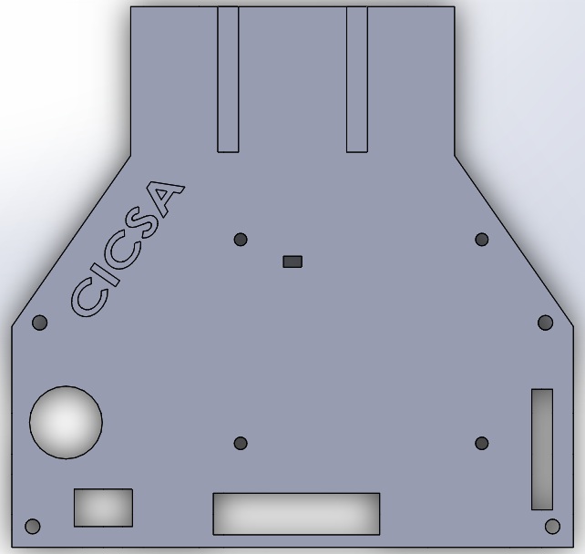
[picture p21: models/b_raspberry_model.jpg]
3D model of the Raspberry Pi 4 base
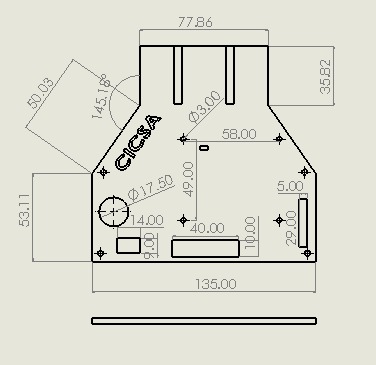
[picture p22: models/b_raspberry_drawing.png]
Technical drawing of the Raspberry Pi 4 base
|  |  |

### 6. Steering Servo Mount - `b_servo`

This base holds the steering servomotor and is installed at the front of the robot.

| 3D model | Technical drawing |
|---|---|
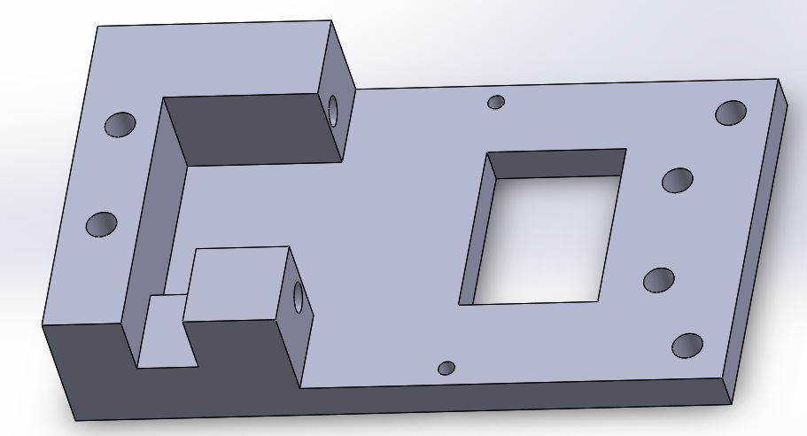
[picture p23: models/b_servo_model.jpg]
3D model of the steering servo mount
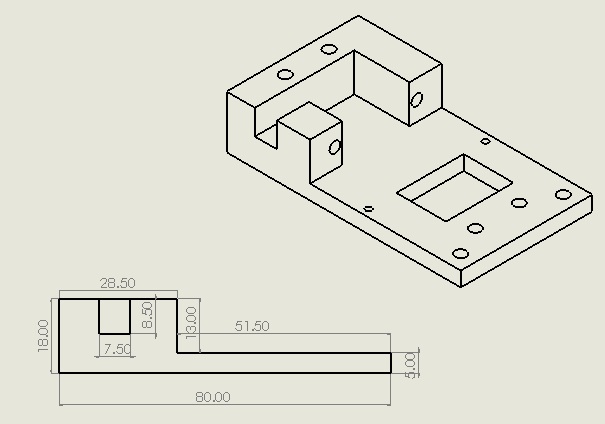
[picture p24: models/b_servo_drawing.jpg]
Technical drawing of the steering servo mount
|  |  |

### 7. Connector-Base Support - `s_b_connector`

This part supports the base that holds the connector assembly.

| 3D model | Technical drawing |
|---|---|
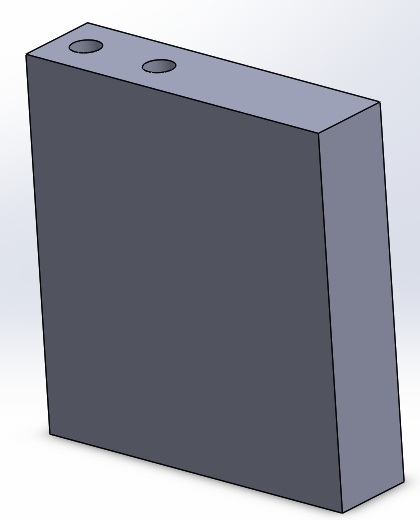
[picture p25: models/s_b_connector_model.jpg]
3D model of the connector-base support
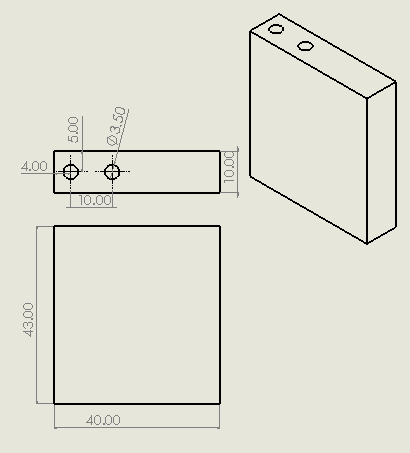
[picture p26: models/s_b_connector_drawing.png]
Technical drawing of the connector-base support
|  |  |

## Manufacturing

All the parts documented in this section were produced using 3D printing. This manufacturing method allowed the team to create components adapted specifically to the robot's mechanical layout and hardware arrangement.

## Design Ownership

All mechanical models presented in this document are original designs developed by our team for the WRO 2026 Future Engineers robot.

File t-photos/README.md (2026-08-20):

Team's photos
====

##here we put the photos of the hole team and how they have been working in the robot

this is a photo of the team

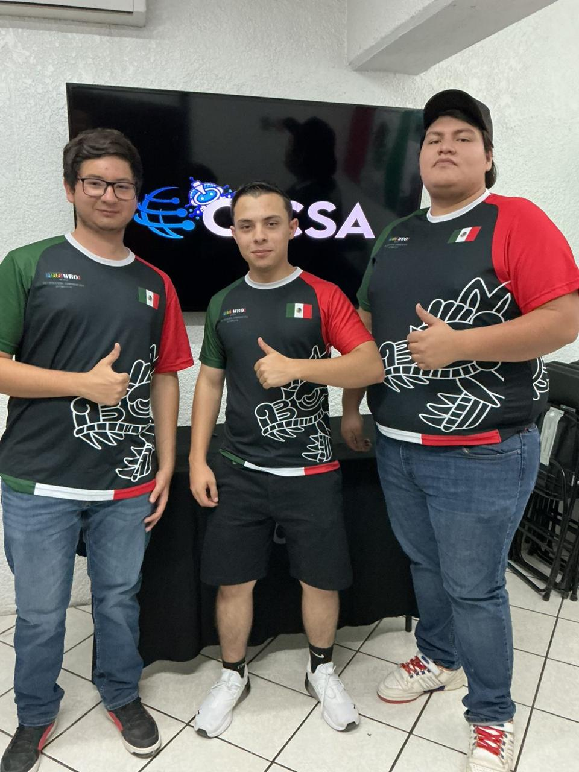
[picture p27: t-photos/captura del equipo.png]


this is a funny photo

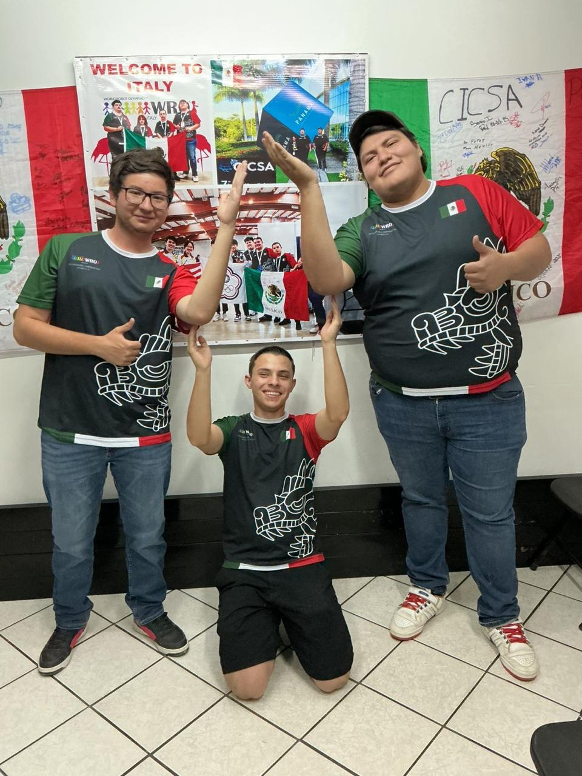
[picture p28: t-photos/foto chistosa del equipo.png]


cb08ea25-18ec-4ffc-ad42-0f671b6e8d55
e0971e59-c212-4669-800a-56bec1d24d39
7747e43b-c620-4904-a211-144c7abf4488

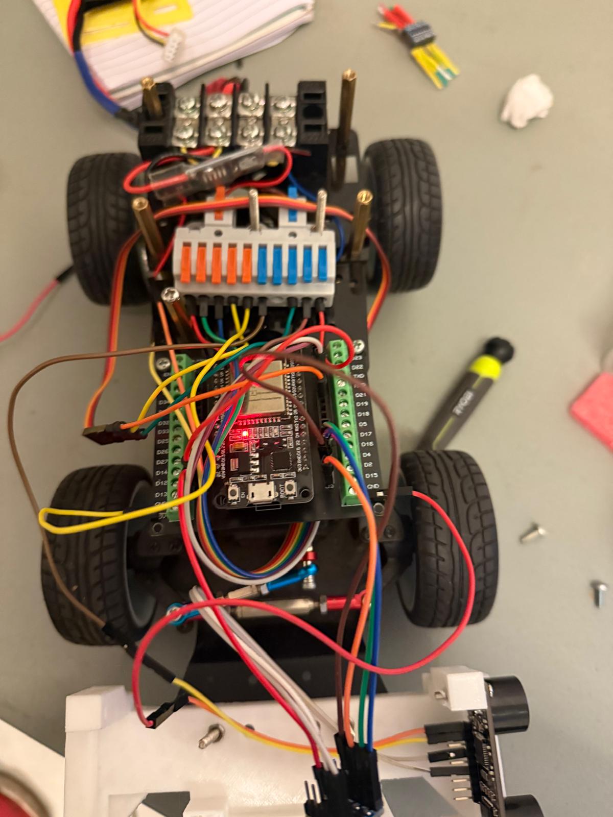
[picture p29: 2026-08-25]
v-photos/robot_version_pasada.jpg

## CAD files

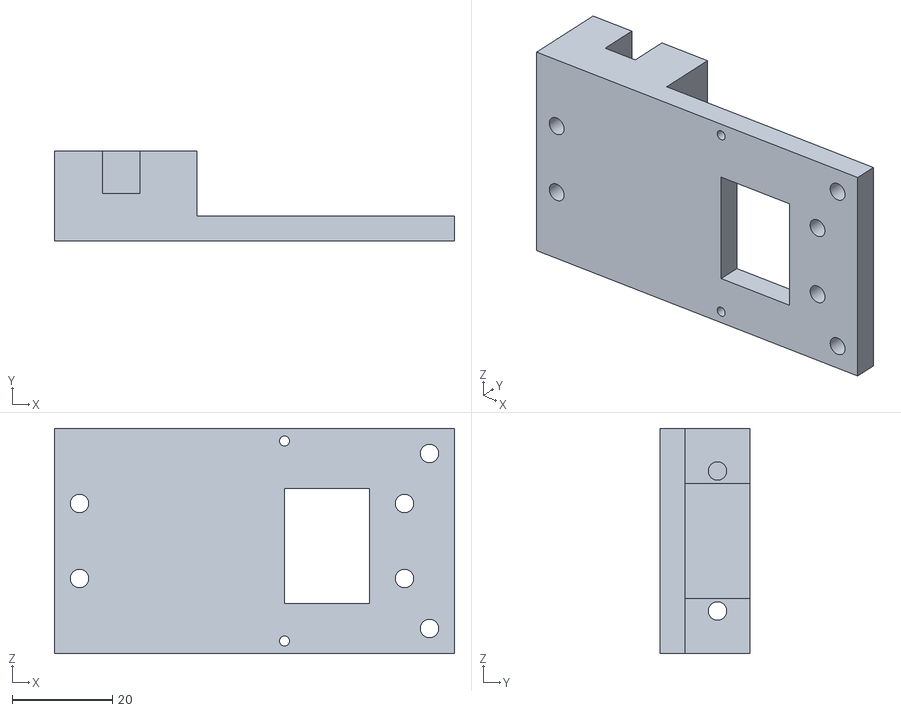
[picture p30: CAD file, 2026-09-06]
models/b_servo.STL
80.0 x 18.0 x 45.0

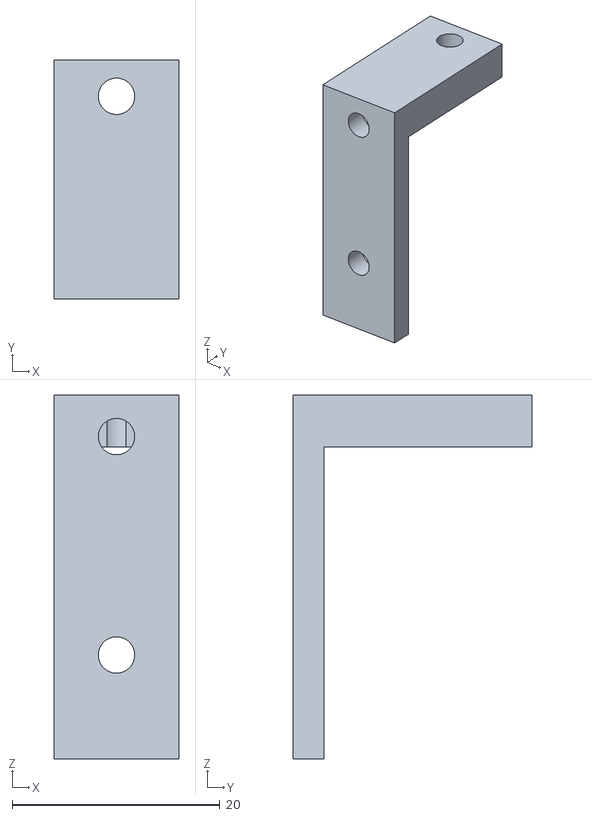
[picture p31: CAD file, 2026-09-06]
models/b_camera.STL
12.0 x 23.0 x 35.0

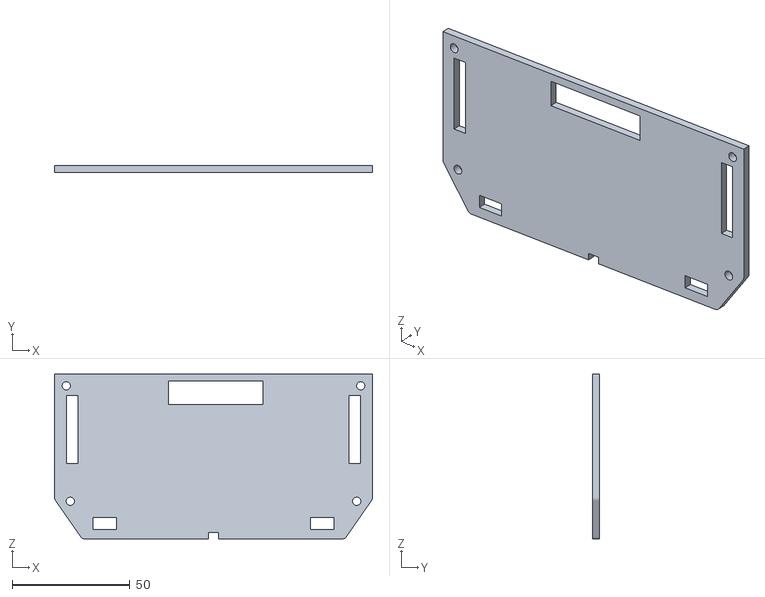
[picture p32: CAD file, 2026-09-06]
models/b_connector.STL
135.0 x 3.00 x 70.0

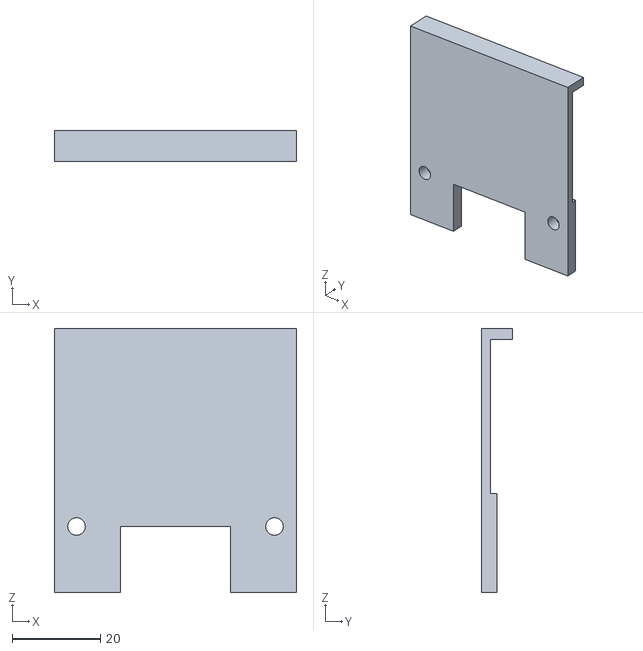
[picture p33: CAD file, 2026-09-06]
models/b_battery.STL
55.0 x 7.00 x 60.0

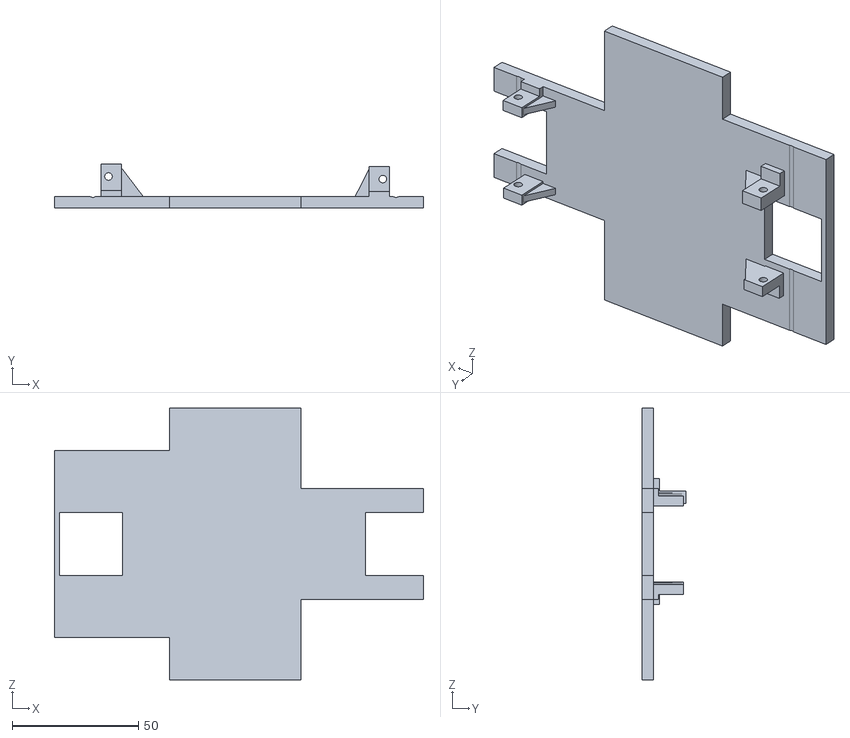
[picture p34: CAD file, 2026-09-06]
models/b_principal.STL
146.0 x 17.5 x 107.6

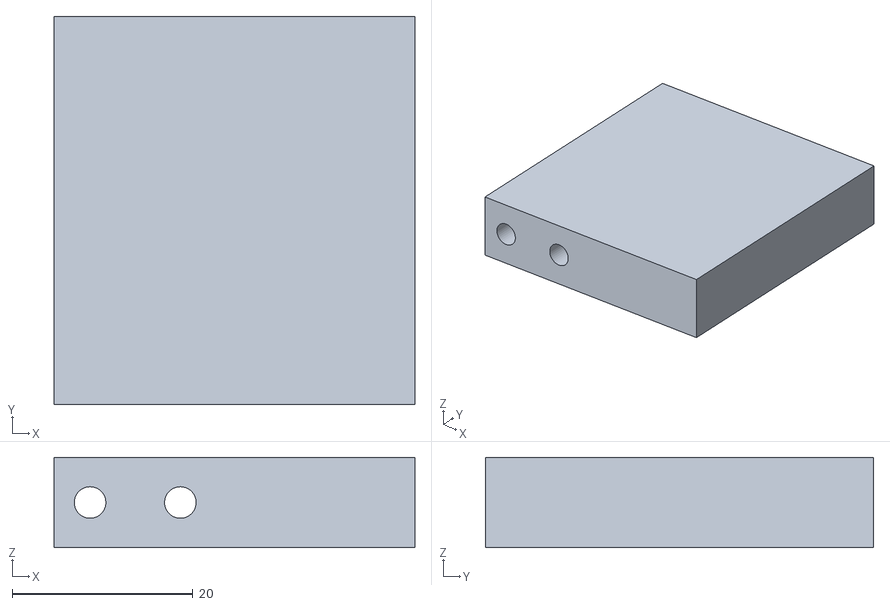
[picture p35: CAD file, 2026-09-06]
models/s_b_connector.STL
40.0 x 43.0 x 10.0

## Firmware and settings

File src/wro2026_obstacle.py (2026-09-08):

#!/usr/bin/env python3
"""WRO 2026 Future Engineers obstacle challenge control program.

Hernández González Sergio Amid
Pereida Arochi Diego
Garcia Audelo Gildardo

The robot uses concurrent LiDAR, camera, and MPU6050 acquisition threads and
a fixed-rate finite-state controller for wall following, pillar avoidance,
cornering, recovery, and telemetry.
"""
import argparse
import csv
import inspect
import math
import os
import sys
import threading
import time
from collections import deque
from dataclasses import dataclass
from enum import Enum, auto
from statistics import median
from typing import Deque, List, Optional, Tuple

SIM = "--sim" in sys.argv
AUTOTEST = "--autotest" in sys.argv

if not SIM and not AUTOTEST:
    os.environ["GPIOZERO_PIN_FACTORY"] = "pigpio"
                                                                  
# General configuration and hardware pins
VERSION = "V6.3-CENTRADO-ARRANQUE"
DEBUG = True
PORT_NAME = "/dev/ttyUSB0"

                                                                         
LAPS = 3
CORNERS_POR_LAP = 4
SECTION_FINAL_S = 0.0                                                         

PIN_MOTOR_IN1 = 23
PIN_MOTOR_IN2 = 22
PIN_SERVO = 12
                                                              
OFFSET_CENTER = -20.0
LIMIT_STEERING_LEFT_DEG = 37.0
LIMIT_STEERING_RIGHT_DEG = 33.0
SERVO_BAND_DEADBAND_DEG = 0.5                                            
                                                                  
BRAKE_PULSE_S = 0.07
BRAKE_SPEED = 0.35
MOTOR_PWM_HZ = None                                                                       
                                                                          
CONTROL_PERIOD_S = 0.025                                           
DISTANCE_LATERAL_TARGET_MM = 430.0
KP_LATERAL = 0.025                                                  
KA_YAW = 0.0                                                                
                                                                                                                                            
KP_DIST_A_HEADING = 0.090                                                 
HEADING_OFFSET_MAX_DEG = 15.0
                                                                          
KI_DIST_A_HEADING = 0.0                                                         
HEADING_INTEGRAL_MAX_DEG = 12.0
KA_HEADING = 1.10                                                               
KD_LATERAL = 0.004                                                             
DERIVADA_MAX_DT_S = 0.35
STEERING_CONTROL_MAX_DEG = 12.0
STEERING_ESCAPE_DEG = 24.0
DISTANCE_ESCAPE_MM = 300.0
DISTANCE_CRITICA_MM = 155.0
DISTANCE_CRITICA_CONFIRMATIONS = 3
                                                                                                            
WALL_MAX_VALIDA_MM = 950.0
WALL_LOST_TIMEOUT_S = 1.5
                                                                                                                             
CARRIL_BLIND_TIMEOUT_S = 2.0
                              
CENTRADO_KP_DEG_POR_MM = 0.020
CENTRADO_MAX_DEG = 10.0

SPEED_STRAIGHT = 0.30
SPEED_APPROACH = 0.20
SPEED_ESCAPE = 0.20
SPEED_EXIT = 0.20

DISTANCE_FRENAR_MM = 950.0
DISTANCE_INICIAR_STEERING_MM = 620.0
FRONT_CRITICAL_MM = 190.0
CONFIRMATIONS_CORNER = 2
TIME_MIN_SECTION_S = 1.0
DISTANCE_DESPEJADO_MM = 800.0                                                                            
                                                              
REVERSE_ANGLE_DEG = 26.0
REVERSE_SPEED = 0.22
REVERSE_FRONT_TARGET_MM = 620.0
REVERSE_TIME_MIN_S = 0.60
REVERSE_TIME_MAX_S = 1.40
STOP_ANTES_DIRECTION_S = 0.35
WAIT_SERVO_REVERSE_S = 0.18
STOP_CAMBIO_GEAR_S = 0.20

                                                                    
STEERING_TARGET_DEG = 85.0
STEERING_SUAVIZAR_DESDE_DEG = 65.0
STEERING_ANGLE_DEG = 32.0
STEERING_ANGLE_FINAL_DEG = 20.0
STEERING_SPEED = 0.23
STEERING_TIME_MIN_S = 0.80
STEERING_TIME_MAX_S = 3.20
STEERING_FRONT_LIBRE_MM = 850.0
STEERING_FRONT_STOP_MM = 220.0
EXIT_STRAIGHT_S = 0.35
MAX_ATTEMPTS_CORNER = 3

                                                               
WALL_NEW_MIN_MM = 200.0
WALL_NEW_MAX_MM = 780.0
WALL_NEW_STABLE_DELTA_MM = 55.0
WALL_NEW_CONFIRMATIONS = 3
WALL_NEW_JUMP_MM = 150.0
WALL_LOST_MIN_S = 0.45
EXIT_CERCA_WALL_MM = 320.0
EXIT_ESCAPE_DEG = 12.0

                                                                             
MAX_RECUPERACIONES = 5
RECOVER_REVERSE_SPEED = 0.20
RECOVER_REVERSE_MAX_S = 1.30
RECOVER_FRONT_LIBRE_MM = 850.0
RECOVER_PAUSA_S = 0.25
                                                                                                                                                  
RECOVER_ANGLE_DEG = 26.0
                                                                                                                          
RECOVER_EXTRA_POR_INTENTO_S = 0.35
                                                              
JUMP_MAX_MM_POR_S = 900.0
                                                                                                                                                   
JUMP_CICLOS_MAX = 6
                                                                             
LIDAR_TIMEOUT_S = 0.85
LIDAR_RETRY_S = 0.8
QUALITY_MIN = 5
DIST_MIN_MM = 100.0
DIST_MAX_MM = 6000.0
LIDAR_OFFSET_DEG = -3.0                                                   
SECTOR_MIN_PUNTOS = 1

FRONT_MIN_DEG = -10.0
FRONT_MAX_DEG = 10.0
REAR_BLIND_MIN_DEG = 130.0
REAR_BLIND_MAX_DEG = 230.0
                                                                        
WALL_THETA_DEG = 25.0
DER_PERP_MIN, DER_PERP_MAX = 85.0, 95.0
DER_FWD_MIN, DER_FWD_MAX = 60.0, 70.0
IZQ_PERP_MIN, IZQ_PERP_MAX = 265.0, 275.0
IZQ_FWD_MIN, IZQ_FWD_MAX = 290.0, 300.0
                                                                         
DER_ANCHO_MIN, DER_ANCHO_MAX = 70.0, 110.0
IZQ_ANCHO_MIN, IZQ_ANCHO_MAX = 250.0, 290.0
YAW_MAX_VALIDO_DEG = 45.0

HISTORY = 3
SECTOR_MAX_AGE_S = 0.35
                                                                            
CAM_W, CAM_H, CAM_FPS = 320, 240, 30
CAMARA_FOCAL_PX = 390.0                                                 
CAM_MAX_AGE_S = 0.35
CAM_AVISO_PERIOD_S = 1.0
VISION_MIN_AREA_PX = 120.0
VISION_CONFIRM_FRAMES = 2
VISION_ALTO_MIN_PX = 6
VISION_ASPECTO_MIN = 0.85                                                                                                         
                                                                           
VISION_FILL_MIN = 0.55
ROI_PILARES = (0.00, 1.00)                                      

HSV_RED1_LO, HSV_RED1_HI = (0, 120, 100), (8, 255, 255)
HSV_RED2_LO, HSV_RED2_HI = (170, 120, 100), (179, 255, 255)
HSV_GREEN_LO, HSV_GREEN_HI = (60, 90, 65), (95, 255, 255)

PILAR_DIST_INICIO_MM = 900.0
PILAR_DIST_REFERENCE_MM = 350.0
PILAR_DIST_STOP_MM = 150.0
PILAR_BOTTOM_INICIO = 0.20
PILAR_BOTTOM_MAX = 0.55
PILAR_STEERING_MIN_DEG = 14.0
PILAR_STEERING_MAX_DEG = 24.0
PILAR_SPEED = 0.20
PILAR_HOLD_RED_S = 0.40
PILAR_HOLD_GREEN_S = 0.35
PILAR_STEERING_EXTRA_GREEN_DEG = 3.0
PILAR_ACTIVATION_BOTTOM = 0.15
PILAR_ACTIVATION_AREA_PX = 250.0
                                                      
PILAR_K_AREA_MM = 24100.0
PILAR_K_BOTTOM_MM = 222.0
PILAR_B_HORIZONTE = 0.165                                                                   
                                                                 
PILAR_B_MINIMUM = 0.20
PILAR_RAZON_MIN = 0.65
PILAR_RAZON_MAX = 1.45
                                                       
PILAR_RAZON_BOTTOM_MAX = 0.75
                                            
PILAR_FRONT_X_MAX = 0.25                                                    
PILAR_FRONT_BOTTOM_MIN = 0.45                                                   
                                                                     
PILAR_TARGET_MM = 260.0                                                                           
                                                                 
PILAR_SIGNAL_MAX_MM = 450.0
                                             
PILAR_HEADING_OFFSET_MAX_DEG = 26.0                                                                         
                   
LIDAR_ANGLE_BLIND_DEG = 20.0                                                                           
                                                                
LIDAR_ANGLE_MAX_USABLE_DEG = 29.0                                                                        
                                        
PILAR_KP_DIST_A_HEADING = 0.20
PILAR_STEERING_CASCADA_MAX_DEG = 28.0                                                                          
                                                           
PILAR_KA_HEADING = 2.5
PILAR_STEERING_LIMITADO_DEG = 8.0                                                                           
                                                                       
PILAR_X_TARGET_RED = 0.25
PILAR_X_TARGET_GREEN = 0.75
PILAR_KP_X = 26.0
PILAR_ADJUSTMENT_MAX_DEG = 10.0
PILAR_X_PASSED_RED = 0.12
PILAR_X_PASSED_GREEN = 0.88                                                                           
                                                
PILAR_REFRACTORY_S = 1.60                                                                            
                                                                             
PILAR_EXIT_SPEED = 0.24                                                               
                                      
PILAR_GAP_MINIMUM_MM = 140.0
PILAR_DISTANCE_CRITICA_MM = 105.0
                                                                
COUNTERSTEER_DEG = 16.0
RECOVERY_SPEED = 0.14
                                                                            
MPU_BUS_I2C = 1
MPU_DIRECCIONES = (0x68, 0x69)
MPU_SAMPLES_CALIBRATION = 1000
MPU_INTERVAL_CALIBRATION_S = 0.002
MPU_FACTOR_GYRO = 131.0
MPU_ZONE_DEADBAND_DPS = 0.35
MPU_FILTER_ALFA = 0.70
MPU_PERIOD_S = 0.005
MPU_DELTA_MIN_EVASION_DEG = 3.0
MPU_TOLERANCE_HEADING_DEG = 1.5
MPU_HEADING_CONFIRMATIONS = 1
MPU_RECOVERY_TIMEOUT_S = 5.00
MPU_COUNTERSTEER_MAX_DEG = 24.0
MPU_COUNTERSTEER_LENTO_DEG = 12.0
MPU_COUNTERSTEER_LENTO_THRESHOLD_DEG = 8.0
                                                                                                                                                     
MPU_SIGN_FIXED: Optional[float] = None
MPU_SIGN_THRESHOLD_DEG = 8.0
VERIFICACION_HEADING_TOLERANCE_DEG = 25.0
                                                                            
TELEMETRIA_ENABLED = True
TELEMETRIA_DIR = "telemetria"
TELEMETRIA_FLUSH_ROWS = 40
                                                                             
if AUTOTEST:
    cv2 = None
    AngularServo = Motor = Picamera2 = RPLidar = SMBus = None
elif SIM:
    from simulacion import (                              
        AngularServo,
        Motor,
        Picamera2,
        RPLidar,
        SMBus,
        mundo,
    )
    cv2 = None
    MPU_SAMPLES_CALIBRATION = 60
else:
    import cv2
    from gpiozero import AngularServo, Motor
    from picamera2 import Picamera2
    from rplidar import RPLidar

    try:
        from smbus2 import SMBus
    except ImportError:
        SMBus = None


NUM_CORNERS = LAPS * CORNERS_POR_LAP

LEFT = "IZQUIERDA"
RIGHT = "DERECHA"


# Finite-state machine states recorded in telemetry
class State(Enum):
    """Code-specific behavior for Estado."""

    START = auto()
    DETERMINE_DIRECTION = auto()
    STRAIGHT = auto()
    PILLAR = auto()
    REVERSE = auto()
    TURN = auto()
    EXIT_TURN = auto()
    RECOVER = auto()
    FINISHED = auto()


class RecoverableError(Exception):
    """Code-specific behavior for Recuperable."""

    def __init__(self, message: str, wall: Optional[str] = None) -> None:
        super().__init__(message)
        self.wall = wall


class Fatal(Exception):
    """Code-specific behavior for Fatal."""


@dataclass(frozen=True)
class Scan:
    front: Optional[float]
    left: Optional[float]
    right: Optional[float]
    yaw_left: Optional[float]
    yaw_right: Optional[float]
    healthy: bool
    seq: int
    age: float


@dataclass(frozen=True)
class Vision:
    color: Optional[str]
    x: Optional[float]
    bottom: float
    area: float
    healthy: bool
    age: float
    seq: int


                                                                             
# Select the mandatory passing side from the pillar color
def evasion_side(color: str) -> str:
    """Code-specific behavior for lado evasion."""
    return LEFT if color == "GREEN" else RIGHT


def reference_wall(color: Optional[str], outer_wall: str) -> str:
    """Code-specific behavior for pared de referencia."""
    return outer_wall if color is None else evasion_side(color)


def is_outer_wall(color: Optional[str], outer_wall: str) -> bool:
    """Code-specific behavior for es pared outer."""
    return reference_wall(color, outer_wall) == outer_wall


def rules_table() -> List[Tuple[str, str, str, str]]:
    """Code-specific behavior for tabla reglamento."""
    filas = []
    for direction, outer_wall in (("clockwise", LEFT),
                                    ("anticlockwise", RIGHT)):
        for color in ("GREEN", "RED"):
            ref = reference_wall(color, outer_wall)
            etiqueta = "outer" if ref == outer_wall else "inner"
            filas.append((direction, color, ref, etiqueta))
    return filas


                                                                             
# Keep the control loop independent of sensor update rates
class FixedRateLoop:
    """Code-specific behavior for Ritmo."""

    def __init__(self, period: float) -> None:
        self.period = period
        self._siguiente = time.monotonic()
        self.overruns = 0

    def reset(self) -> None:
        self._siguiente = time.monotonic()

    def wait(self) -> float:
        self._siguiente += self.period
        now = time.monotonic()
        remaining = self._siguiente - now
        if remaining > 0:
            time.sleep(remaining)
            return self._siguiente
        if remaining < -self.period:
            self.overruns += 1
            self._siguiente = now
        return now


                                                                             
# Store time-stamped control and sensor data in CSV format
class Telemetry:
    """Code-specific behavior for Telemetria."""

    CAMPOS = [
        "t", "estado", "esquina", "d", "ref", "obj", "d_izq", "d_der",
        "front", "yaw", "cmd", "vel", "pilar", "pilar_x", "pilar_b",
        "rumbo", "rumbo_rel", "lidar_ok", "vision_ok",
    ]

    def __init__(self) -> None:
        self._archivo = None
        self._writer = None
        self._filas = 0
        self._t0 = time.monotonic()
        self.ruta: Optional[str] = None

    def open(self) -> None:
        if not TELEMETRIA_ENABLED:
            return
        try:
            os.makedirs(TELEMETRIA_DIR, exist_ok=True)
            marca = time.strftime("%Y%m%d_%H%M%S")
            self.ruta = os.path.join(TELEMETRIA_DIR, f"run_{marca}.csv")
            self._archivo = open(self.ruta, "w", newline="")
            self._writer = csv.writer(self._archivo)
            self._writer.writerow(self.CAMPOS)
            print(f"TELEMETRIA: {self.ruta}")
        except Exception as exc:
            print("TELEMETRY UNAVAILABLE:", exc)
            self._archivo = None
            self._writer = None

    def write_row(self, **kwargs) -> None:
        if self._writer is None:
            return
        kwargs.setdefault("t", round(time.monotonic() - self._t0, 3))
        try:
            self._writer.writerow(
                [kwargs.get(campo, "") for campo in self.CAMPOS]
            )
            self._filas += 1
            if self._filas % TELEMETRIA_FLUSH_ROWS == 0:
                self._archivo.flush()
        except Exception:
            pass

    def close(self) -> None:
        if self._archivo is not None:
            try:
                self._archivo.flush()
                self._archivo.close()
                print(f"TELEMETRIA GUARDADA: {self.ruta} ({self._filas} filas)")
            except Exception:
                pass
            self._archivo = None
            self._writer = None
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

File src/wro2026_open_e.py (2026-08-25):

import threading
from rplidar import RPLidar
import os
# Force pigpio factory for hardware-timed, jitter-free PWM signals
os.environ['GPIOZERO_PIN_FACTORY'] = 'pigpio'
from gpiozero import Motor, AngularServo
import time
import numpy as np
from scipy.ndimage import median_filter
import logging
from collections import deque

# ==============================================================================
#    GPIO PIN CONFIGURATION
# ==============================================================================
# AWD Drivetrain (DRV8871 H-Bridge Drivers)
PIN_FRONT_IN1 = 17
PIN_FRONT_IN2 = 18
PIN_REAR_IN1 = 23
PIN_REAR_IN2 = 22
MOTOR_FRONT_FLAG = False  # Toggle front-axle engagement for efficiency/testing

# Steering Actuator
PIN_SERVO_SIGNAL = 12

# ==============================================================================
#    HARDWARE CALIBRATION & PARAMETERS
# ==============================================================================
# 1. AWD Drivetrain Power Balancing:
FACTOR_FRONT = 1.00  # Front axle power scaling coefficient (0.0 to 1.0)
FACTOR_REAR  = 1.00  # Rear axle power scaling coefficient (0.0 to 1.0)

# 2. Steering Kinematics Calibration:
CENTER_OFFSET = -20   # Mechanical alignment offset (negative value trims right)
STEERING_LIMIT = 40  # Maximum permissible steering angle to prevent binding

# ==============================================================================
#    HARDWARE INITIALIZATION
# ==============================================================================
# H-Bridge DC Motor Actuators
motor_front = Motor(forward=PIN_FRONT_IN1, backward=PIN_FRONT_IN2)
motor_rear  = Motor(forward=PIN_REAR_IN1,  backward=PIN_REAR_IN2)

# High-Resolution PWM Steering Servo
steering = AngularServo(
    12, 
    min_angle=-90, 
    max_angle=90, 
    min_pulse_width=0.0005, 
    max_pulse_width=0.0025, 
    initial_angle=0
)

# ==============================================================================
#    LIDAR SENSOR CONFIGURATION
# ==============================================================================
PORT_NAME = "/dev/ttyUSB0"

# Spatial partitioning thresholds (in degrees) to segment point clouds
ANGULO_FRONT_MIN = -5
ANGULO_FRONT_MAX = 5

ANGULO_LEFT_MIN = 255
ANGULO_LEFT_MAX = 285

ANGULO_RIGHT_MIN = 75
ANGULO_RIGHT_MAX = 105

# --- Thread-Safe Global State Variables per Region of Interest (ROI) ---
lidar_distance_front = None
lidar_distance_left = None
lidar_distance_right = None

lidar_running = True
lidar_lock = threading.Lock()  # Mutex lock to guarantee thread safety and prevent race conditions

# ==============================================================================
#    GLOBAL NAVIGATION STATE
# ==============================================================================
control_direction = ""  # Defines active reference wall ("LEFT" or "RIGHT")
target_velocity = 0.5   # Base duty cycle for drivetrain speed control
telemetry_data = []     # Historical log array for post-run analysis
control_history = deque(maxlen=5)  # Circular buffer for discrete signal filtering

# ==============================================================================
#    STEERING CONTROL SUBSYSTEM
# ==============================================================================
def set_steering_angle(desired_angle):
    """
    Executes constrained geometric steering control.
    Convention: 0° = Rectilinear, Positive = Left Turn, Negative = Right Turn.
    """
    # 1. Structural bounding box to protect mechanical linkages
    safe_angle = min(max(desired_angle, -STEERING_LIMIT), STEERING_LIMIT)
    
    # 2. Apply linear mapping offset for zero-point chassis calibration
    final_angle = safe_angle + CENTER_OFFSET
    
    # 3. Dispatched hardware command via PWM duty cycle
    steering.angle = final_angle

# ==============================================================================
#    DRIVETRAIN ACTUATION SUBSYSTEM
# ==============================================================================
def drive_forward_awd(base_velocity):
    """Propels the vehicle forward scaling current duty cycles by axle-specific constants."""
    vel_front = min(max(base_velocity * FACTOR_FRONT, 0.0), 1.0)
    vel_rear  = min(max(base_velocity * FACTOR_REAR, 0.0), 1.0)
    
    if MOTOR_FRONT_FLAG:
        motor_front.forward(speed=vel_front)
    motor_rear.forward(speed=vel_rear)

def drive_backward_awd(base_velocity):
    """Reverses the vehicle using the calibrated traction balancing model."""
    vel_front = min(max(base_velocity * FACTOR_FRONT, 0.0), 1.0)
    vel_rear  = min(max(base_velocity * FACTOR_REAR, 0.0), 1.0)
    
    if MOTOR_FRONT_FLAG:
        motor_front.backward(speed=vel_front)
    motor_rear.backward(speed=vel_rear)

def stop_awd():
    """Forces an immediate zero-power electronic stop across the AWD system."""
    motor_front.stop()
    motor_rear.stop()
    
# ==============================================================================
#    DIGITAL SIGNAL PROCESSING & PERCEPTION (LIDAR)
# ==============================================================================
def filter_lidar_zone(point_cloud_roi, dist_min=150.0, dist_max=6000.0, window_size=3, step_threshold=500.0):
    """
    Vectorized Digital Signal Processing (DSP) pipeline optimized using NumPy.
    Smooths data, handles outlier reflection rejections, and avoids CPU blocking.
    """
    n_points = len(point_cloud_roi)
    if n_points < window_size:
        return point_cloud_roi

    # 1. High-speed array conversion and quick-sorting by heading
    raw_data = np.array(point_cloud_roi)  # Structure: [[distance, angle], ...]
    raw_data = raw_data[raw_data[:, 1].argsort()]

    distances = raw_data[:, 0]
    angles = raw_data[:, 1]

    # 2. Hard Threshold Bandpass Range Filter
    valid_range_mask = (distances >= dist_min) & (distances <= dist_max)
    if not np.any(valid_range_mask):
        return []

    # Linear interpolation to substitute out-of-range sensor dropouts safely
    filtered_distances = np.interp(
        np.arange(n_puntos:=n_points),
        np.where(valid_range_mask)[0],
        distances[valid_range_mask],
    )

    # 3. Non-linear Median Filtering to eliminate specular multi-path reflections
    filtered_distances = median_filter(filtered_distances, size=window_size, mode="wrap")

    # 4. Step Discontinuity Mitigation (First-order derivative filtering)
    gradients = np.abs(np.diff(filtered_distances, prepend=filtered_distances[-1]))
    stable_gradient_mask = gradients <= step_threshold

    # Compound boolean conditional index mask
    optimized_mask = valid_range_mask & stable_gradient_mask

    # 5. Native reconstruction recovery for consumer loops
    return list(zip(filtered_distances[optimized_mask], angles[optimized_mask]))
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

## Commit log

2026-02-11 power architecture and sensor
2026-02-11 Update power architecture and sensor
2026-03-18 Create Sensors and Motors
2026-05-20 Update README.md
    prices of the pieces, ultrasonic and an aproximation of the final price of the robot
2026-08-25 Agosto 24 added battery change
